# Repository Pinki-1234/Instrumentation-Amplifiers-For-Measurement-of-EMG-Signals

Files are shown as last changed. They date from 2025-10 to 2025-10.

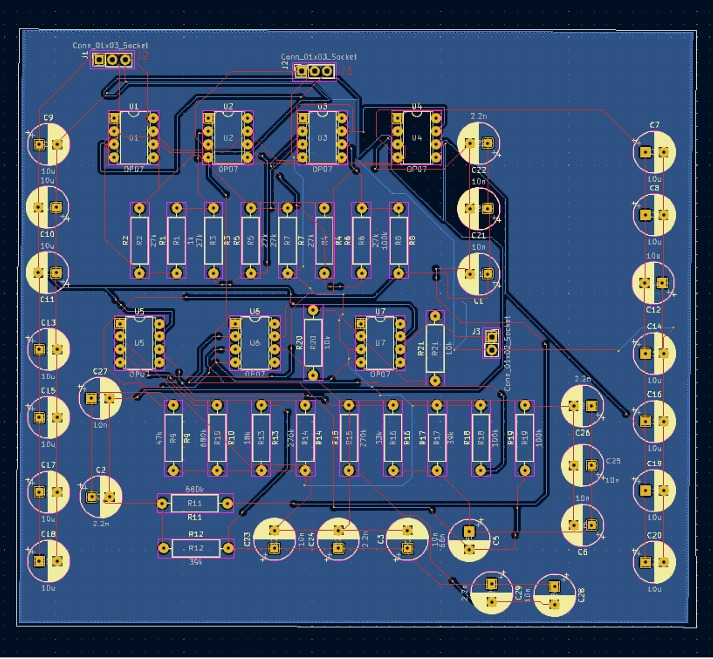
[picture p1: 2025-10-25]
PCB design.jpeg

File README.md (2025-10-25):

# Instrumentation Amplifiers for Measurement of EMG Signals

## Overview
This project focuses on designing and building an **Instrumentation Amplifier Circuit** specifically for measuring **Electromyography (EMG)** signals.  
The EMG signal is a bioelectrical signal produced by skeletal muscles, generally spanning **0.1 mV–5 mV** in amplitude and occupying a frequency range of **0–500 Hz**.  
To accurately capture and amplify this low-frequency, low-amplitude signal, the circuit design integrates both **high CMRR instrumentation amplification** and **selective bandpass filtering**, ensuring minimal noise interference and maximum fidelity.

---

## Objectives
- To design a **low-noise instrumentation amplifier** for biomedical EMG signal acquisition.  
- To achieve optimal **common-mode noise rejection** and **signal integrity**.  
- To implement a **bandpass filter** that passes frequencies relevant to EMG (50–150 Hz).  
- To validate the design using circuit simulations and performance testing.

---

## Project Architecture
The system is divided into two core functional blocks:

### 1. Instrumentation Amplifier Block
- Built using a **three-op-amp configuration** based on **OP07** operational amplifiers.  
- Provides high input impedance, excellent stability, and precise gain control.  
- Achieves an experimental gain of approximately **54 V/V**, aligning closely with the expected **55 V/V** value.  
- Ensures **high CMRR**, effectively filtering out common-mode interference and power-line noise.

### 2. Bandpass Filter Block
- Implements a **6th-order active bandpass filter** with a passband between **50 Hz and 250 Hz**.  
- Designed to preserve the EMG signal energy (primarily in 50–150 Hz) while blocking unwanted components.  
- Demonstrated strong attenuation of frequencies at **20 Hz** and **1 kHz**, confirming the filter’s effective roll-off characteristics.

---

## Circuit Design and Components
The project employs through-hole components, structured using **KiCad PCB Design Tools**.

### Key Components
- **ICs:** OP07 (x7)  
- **Resistors:** Ranging between 1 kΩ to 680 kΩ  
- **Capacitors:** 2.2 nF to 10 µF (radial THT)  
- **Connectors:** 2.54 mm pitch sockets for input/output  
- **Power Supply:** ±12 V DC dual supply  

### Tools Used
- **Simulation:** Tektronix TBS1072B Digital Oscilloscope  
- **PCB Design:** KiCad (schematic capture, footprint assignment, ERC, DRC)  
- **3D Visualization:** KiCad 3D Model View  

---

## Results and Testing

### Instrumentation Amplifier Testing:
- **Input:** 2 mV (differential, 180° out of phase)  
- **Output:** 216 mV  
- **Gain:** ~54 V/V (validated via oscilloscope readings)

### Filter Testing:
- **Input:** 100 mV sine wave at various frequencies  
- **20 Hz →** Output attenuated heavily  
- **100 Hz →** Signal passed cleanly  
- **1 kHz →** Output significantly reduced  

This confirms the amplifier–filter chain delivers the desired selective response and accuracy for EMG signal acquisition.

---

## PCB Design
The PCB was designed for compactness and low interference:

- **Schematic Capture:** Completed with correct symbol–footprint mapping  
- **Electrical Rule Check (ERC):** No major unconnected items or design violations  
- **Design Rule Check (DRC):** Verified compliance with layout standards  
- **3D View:** Ensured precise component placement for manufacturing  

---

## Applications
- Biomedical instrumentation, specifically **EMG signal measurement**  
- Medical research and muscle activity analysis  
- Biosignal processing and human–machine interface systems  
- Educational projects for analog circuit design and bioelectronics

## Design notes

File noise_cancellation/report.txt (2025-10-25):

Info: Processing symbol 'C1:Capacitor_SMD:C_0805_2012Metric'.
Info: Processing symbol 'C2:Capacitor_SMD:C_0805_2012Metric'.
Info: Processing symbol 'C3:Capacitor_SMD:C_0805_2012Metric'.
Info: Processing symbol 'C5:Capacitor_SMD:C_0805_2012Metric'.
Info: Processing symbol 'C6:Capacitor_SMD:C_0805_2012Metric'.
Info: Processing symbol 'C7:Capacitor_SMD:C_0805_2012Metric'.
Info: Processing symbol 'C8:Capacitor_SMD:C_0805_2012Metric'.
Info: Processing symbol 'C14:Capacitor_SMD:C_0805_2012Metric'.
Info: Processing symbol 'C9:Capacitor_SMD:C_0805_2012Metric'.
Info: Processing symbol 'C10:Capacitor_SMD:C_0805_2012Metric'.
Info: Processing symbol 'U5:Package_DIP:DIP-8_W7.62mm'.
Info: Processing symbol 'C11:Capacitor_SMD:C_0805_2012Metric'.
Info: Processing symbol 'C12:Capacitor_SMD:C_0805_2012Metric'.
Info: Processing symbol 'C13:Capacitor_SMD:C_0805_2012Metric'.
Info: Processing symbol 'U6:Package_DIP:DIP-8_W7.62mm'.
Info: Processing symbol 'C15:Capacitor_SMD:C_0805_2012Metric'.
Info: Processing symbol 'C16:Capacitor_SMD:C_0805_2012Metric'.
Info: Processing symbol 'C17:Capacitor_SMD:C_0805_2012Metric'.
Info: Processing symbol 'C18:Capacitor_SMD:C_0805_2012Metric'.
Info: Processing symbol 'C19:Capacitor_SMD:C_0805_2012Metric'.
Info: Processing symbol 'C20:Capacitor_SMD:C_0805_2012Metric'.
Info: Processing symbol 'C21:Capacitor_SMD:C_0805_2012Metric'.
Info: Processing symbol 'C22:Capacitor_SMD:C_0805_2012Metric'.
Info: Processing symbol 'C23:Capacitor_SMD:C_0805_2012Metric'.
Info: Processing symbol 'C24:Capacitor_SMD:C_0805_2012Metric'.
Info: Processing symbol 'C25:Capacitor_SMD:C_0805_2012Metric'.
Info: Processing symbol 'C26:Capacitor_SMD:C_0805_2012Metric'.
Info: Processing symbol 'C27:Capacitor_SMD:C_0805_2012Metric'.
Info: Processing symbol 'C28:Capacitor_SMD:C_0805_2012Metric'.
Info: Processing symbol 'C29:Capacitor_SMD:C_0805_2012Metric'.
Info: Processing symbol 'J1:Connector_PinSocket_2.54mm:PinSocket_1x03_P2.54mm_Vertical'.
Info: Processing symbol 'J2:Connector_PinSocket_2.54mm:PinSocket_1x03_P2.54mm_Vertical'.
Info: Processing symbol 'J3:Connector_PinSocket_2.54mm:PinSocket_1x02_P2.54mm_Vertical'.
Info: Processing symbol 'R1:Resistor_SMD:R_0805_2012Metric'.
Info: Processing symbol 'R2:Resistor_SMD:R_0805_2012Metric'.
Info: Processing symbol 'R3:Resistor_SMD:R_0805_2012Metric'.
Info: Processing symbol 'R4:Resistor_SMD:R_0805_2012Metric'.
Info: Processing symbol 'R5:Resistor_SMD:R_0805_2012Metric'.
Info: Processing symbol 'R6:Resistor_SMD:R_0805_2012Metric'.
Info: Processing symbol 'R7:Resistor_SMD:R_0805_2012Metric'.
Info: Processing symbol 'R8:Resistor_SMD:R_0805_2012Metric'.
Info: Processing symbol 'R9:Resistor_SMD:R_0805_2012Metric'.
Info: Processing symbol 'R10:Resistor_SMD:R_0805_2012Metric'.
Info: Processing symbol 'R11:Resistor_SMD:R_0805_2012Metric'.
Info: Processing symbol 'R12:Resistor_SMD:R_0805_2012Metric'.
Info: Processing symbol 'R13:Resistor_SMD:R_0805_2012Metric'.
Info: Processing symbol 'R14:Resistor_SMD:R_0805_2012Metric'.
Info: Processing symbol 'R15:Resistor_SMD:R_0805_2012Metric'.
Info: Processing symbol 'R16:Resistor_SMD:R_0805_2012Metric'.
Info: Processing symbol 'R17:Resistor_SMD:R_0805_2012Metric'.
Info: Processing symbol 'R18:Resistor_SMD:R_0805_2012Metric'.
Info: Processing symbol 'R19:Resistor_SMD:R_0805_2012Metric'.
Info: Processing symbol 'R20:Resistor_SMD:R_0805_2012Metric'.
Info: Processing symbol 'R21:Resistor_SMD:R_0805_2012Metric'.
Info: Processing symbol 'U1:Package_DIP:DIP-8_W7.62mm'.
Info: Processing symbol 'U7:Package_DIP:DIP-8_W7.62mm'.
Info: Processing symbol 'U2:Package_DIP:DIP-8_W7.62mm'.
Info: Processing symbol 'U3:Package_DIP:DIP-8_W7.62mm'.
Info: Processing symbol 'U4:Package_DIP:DIP-8_W7.62mm'.
Reconnected C10 pin 2 from Net-(J1-Pin_2) to Net-(J1-Pin_1).
Reconnected C8 pin 1 from Net-(J1-Pin_1) to Net-(J1-Pin_2).
Reconnected U1 pin 4 from Net-(J1-Pin_1) to Net-(J1-Pin_2).
Reconnected U1 pin 7 from Net-(J1-Pin_2) to Net-(J1-Pin_1).

Info: Total warnings: 0, errors: 0.

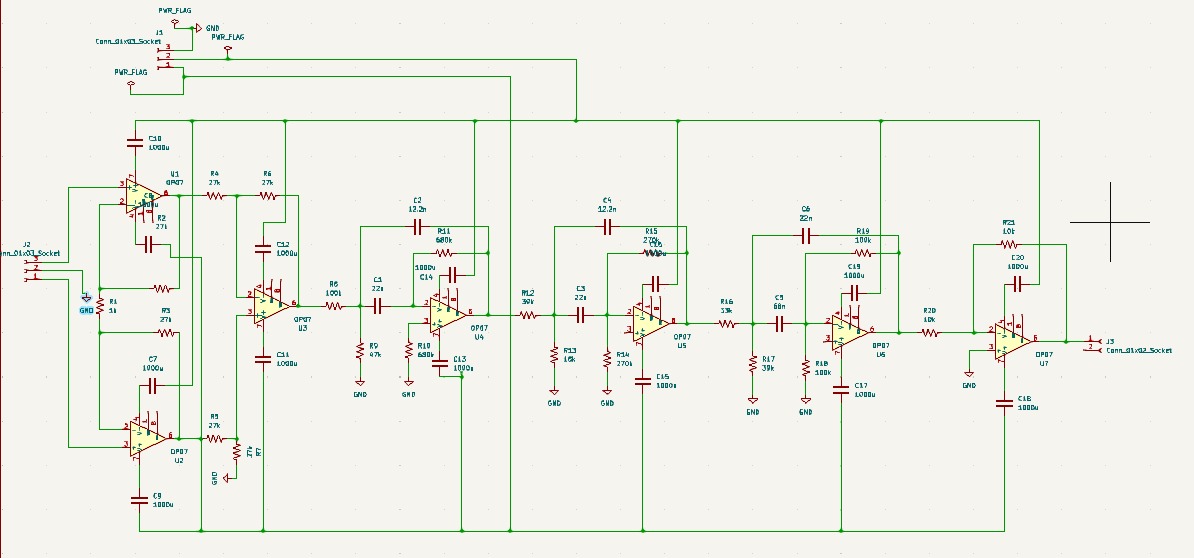
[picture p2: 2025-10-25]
Schematic diagram.jpeg

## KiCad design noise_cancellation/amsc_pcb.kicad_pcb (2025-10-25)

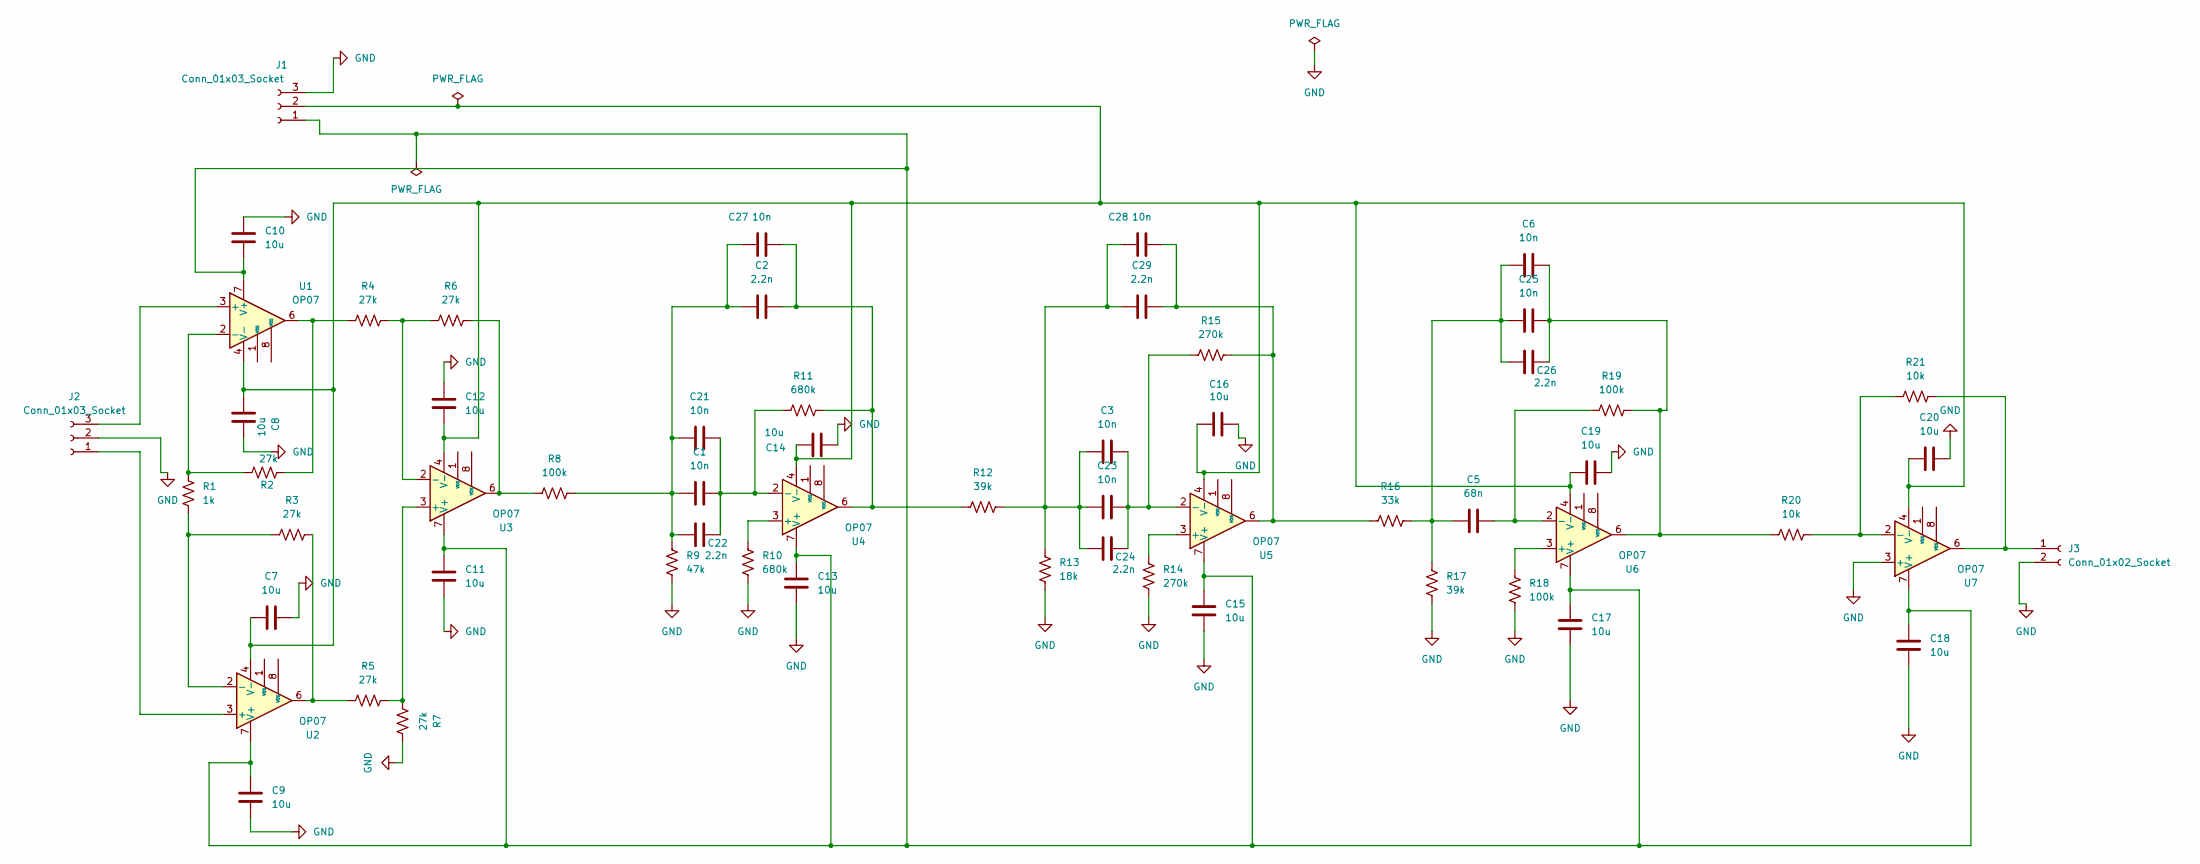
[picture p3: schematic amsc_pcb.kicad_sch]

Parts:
C1, C3, C6, C21, C23, C25, C27, C28: 10n; CP_Radial_D8.0mm_P3.50mm
C2, C22, C24, C26, C29: 2.2n; CP_Radial_D8.0mm_P3.50mm
C5: 68n; CP_Radial_D8.0mm_P3.50mm
C7, C8, C9, C10, C11, C12, C13, C14, C15, C16, C17, C18, C19, C20: 10u; CP_Radial_D8.0mm_P3.50mm
J1, J2: Conn_01x03_Socket; PinSocket_1x03_P2.54mm_Vertical
J3: Conn_01x02_Socket; PinSocket_1x02_P2.54mm_Vertical
R1: 1k; R_Axial_DIN0309_L9.0mm_D3.2mm_P12.70mm_Horizontal
R2, R3, R4, R5, R6, R7: 27k; R_Axial_DIN0309_L9.0mm_D3.2mm_P12.70mm_Horizontal
R8, R18, R19: 100k; R_Axial_DIN0309_L9.0mm_D3.2mm_P12.70mm_Horizontal
R9: 47k; R_Axial_DIN0309_L9.0mm_D3.2mm_P12.70mm_Horizontal
R10, R11: 680k; R_Axial_DIN0309_L9.0mm_D3.2mm_P12.70mm_Horizontal
R12, R17: 39k; R_Axial_DIN0309_L9.0mm_D3.2mm_P12.70mm_Horizontal
R13: 18k; R_Axial_DIN0309_L9.0mm_D3.2mm_P12.70mm_Horizontal
R14, R15: 270k; R_Axial_DIN0309_L9.0mm_D3.2mm_P12.70mm_Horizontal
R16: 33k; R_Axial_DIN0309_L9.0mm_D3.2mm_P12.70mm_Horizontal
R20, R21: 10k; R_Axial_DIN0309_L9.0mm_D3.2mm_P12.70mm_Horizontal
U1, U2, U3, U4, U5, U6, U7: OP07; DIP-8_W7.62mm

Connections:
GND: C7.2, C8.2, C9.2, C10.1, C11.1, C12.1, C13.2, C14.2, C15.2, C16.2, C17.2, C18.2, C19.2, C20.2, J1.3, J2.2, J3.2, R7.2, R9.2, R10.2, R13.2, R14.2, R17.2, R18.2, U7.3 (+)
unnamed: C1.1, C2.1, C21.1, C22.1, C27.1, R8.2, R9.1
unnamed: C2.2, C27.2, R11.2, R12.1, U4.6
unnamed: C3.1, C23.1, C24.1, C28.1, C29.1, R12.2, R13.1
unnamed: C5.1, C6.1, C25.1, C26.1, R16.2, R17.1
unnamed: C6.2, C25.2, C26.2, R19.2, R20.1, U6.6
unnamed: C28.2, C29.2, R15.2, R16.1, U5.6
unnamed: C9.1, C10.2, C11.2, C13.1, C15.1, C17.1, C18.1, J1.1, U1.7 (V+), U2.7 (V+), U3.7 (V+), U4.7 (V+), U5.7 (V+), U6.7 (V+), U7.7 (V+)
unnamed: C7.1, C8.1, C12.2, C14.1, C16.1, C19.1, C20.1, J1.2, U1.4 (V-), U2.4 (V-), U3.4 (V-), U4.4 (V-), U5.4 (V-), U6.4 (V-), U7.4 (V-)
unnamed: J2.1, U2.3 (+)
unnamed: J2.3, U1.3 (+)
unnamed: J3.1, R21.2, U7.6
unnamed: R2.2, R4.1, U1.6
unnamed: R3.2, R5.1, U2.6
unnamed: R6.2, R8.1, U3.6
unnamed: R1.1, R2.1, U1.2 (-)
unnamed: R1.2, R3.1, U2.2 (-)
unnamed: R5.2, R7.1, U3.3 (+)
unnamed: R4.2, R6.1, U3.2 (-)
unnamed: R10.1, U4.3 (+)
unnamed: C1.2, C21.2, C22.2, R11.1, U4.2 (-)
unnamed: R14.1, U5.3 (+)
unnamed: C3.2, C23.2, C24.2, R15.1, U5.2 (-)
unnamed: R18.1, U6.3 (+)
unnamed: C5.2, R19.1, U6.2 (-)
unnamed: R20.2, R21.1, U7.2 (-)

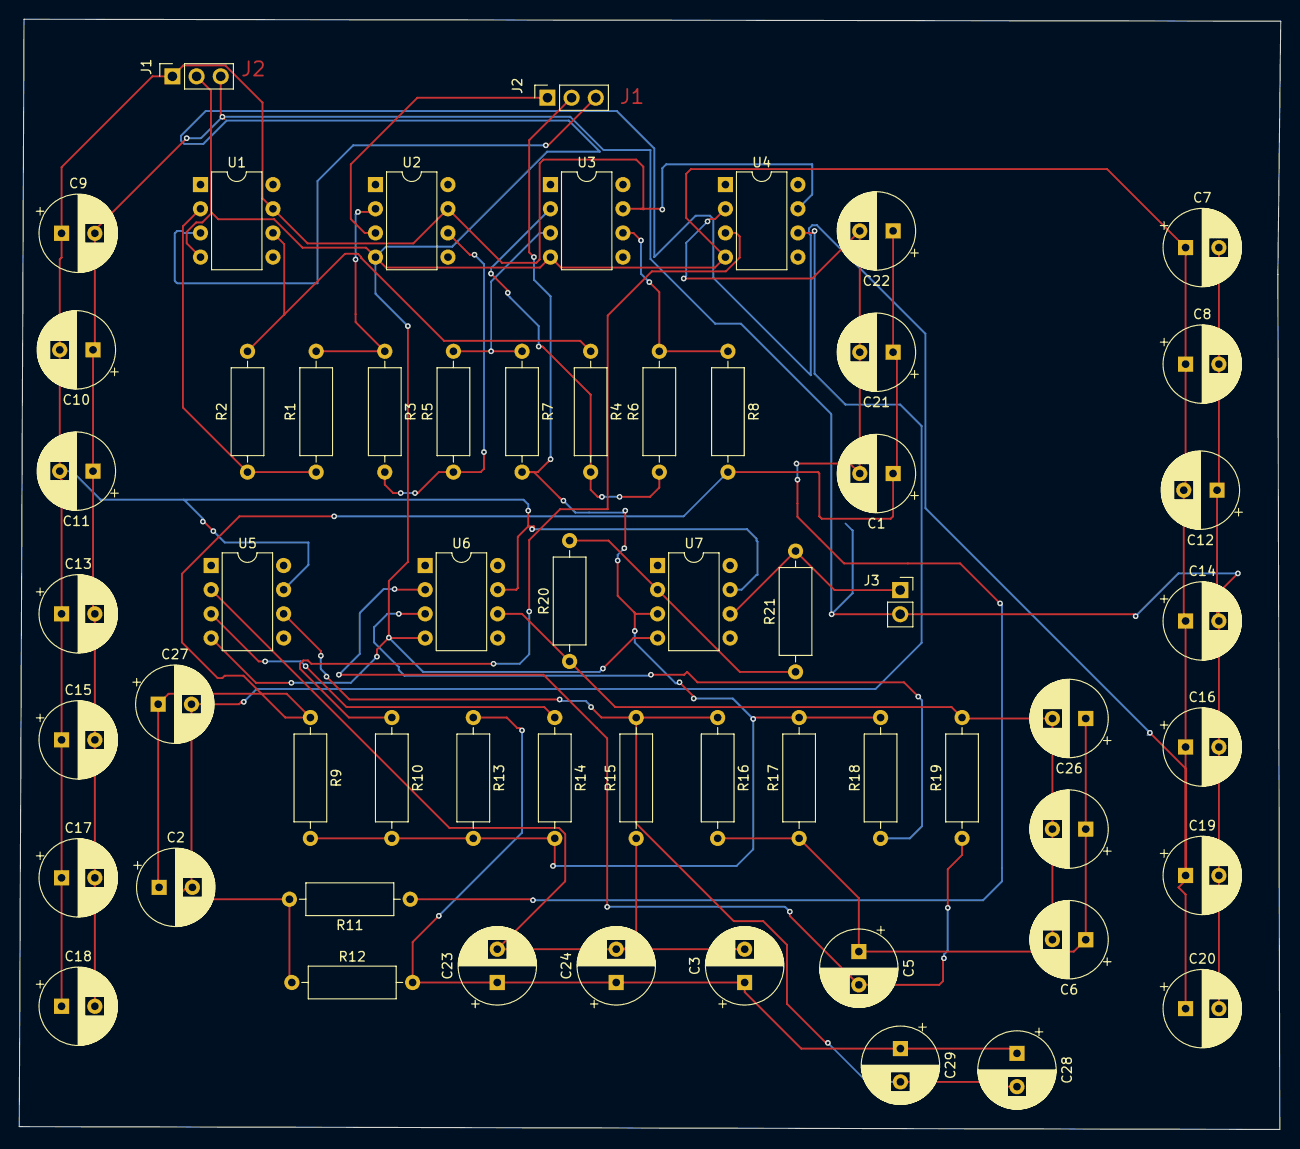
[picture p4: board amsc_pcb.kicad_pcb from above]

Board: 2 copper layers, 132.6 x 116.7 mm, 59 parts (0 on the bottom side), 26 nets.

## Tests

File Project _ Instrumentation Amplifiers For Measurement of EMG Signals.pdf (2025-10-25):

Project Title: Instrumentation Amplifiers For Measurement of EMG Signals TA Name: Sapna kumari

The project aims to design and build a low-noise amplifier tailored for EMG (electromyography) signals, which typically have low voltages ranging from 0.1 mV to 5 mV and frequencies between 0 and 500 Hz. EMG signals are inherently delicate, and most of the signal's energy is concentrated in the 50 to 150 Hz range. This project seeks to amplify these low-voltage signals effectively while minimizing noise, ensuring the amplified signal retains its original characteristics as closely as possible.

To achieve these goals, the design is divided into two main functional blocks:

1. Instrumentation Amplifier Block:
This first block uses a three-op-amp instrumentation amplifier configuration, chosen for its high common-mode rejection ratio (CMRR) and low power consumption. An instrumentation amplifier is essential here because it will reduce common-mode noise, which can arise from environmental interference or other external sources. By canceling this common noise, the instrumentation amplifier ensures that the useful EMG signal is preserved and amplified accurately. This configuration is particularly effective for biomedical applications due to its ability to handle differential signals and its stable gain settings.
2. Bandpass Filter Block:
Following the instrumentation amplifier, the signal passes through a 6th-order bandpass filter, specifically designed to pass frequencies within a range of 50 Hz to 250 Hz. This range includes the frequency band where most of the EMG signal's energy resides (50 to 150 Hz) while filtering out noise outside this band. The 6th-order design provides a steep roll-off outside the passband, which helps further reduce any unwanted low-frequency drift and high-frequency noise, resulting in a cleaner signal. The filter’s bandwidth is set at approximately 200 Hz, allowing for an effective trade-off between filtering precision and preserving the essential components of the EMG signal.

This amplifier is designed for EMG applications, where low noise and signal integrity are critical. The combination of a high-quality instrumentation amplifier and a selective bandpass filter ensures that the final amplified signal is both clear and highly representative of the original EMG activity. This approach is commonly used in biomedical engineering, where capturing accurate physiological signals is vital for reliable analysis and diagnostics.

Instrumentation amplifier Block:

Circuit Diagram:

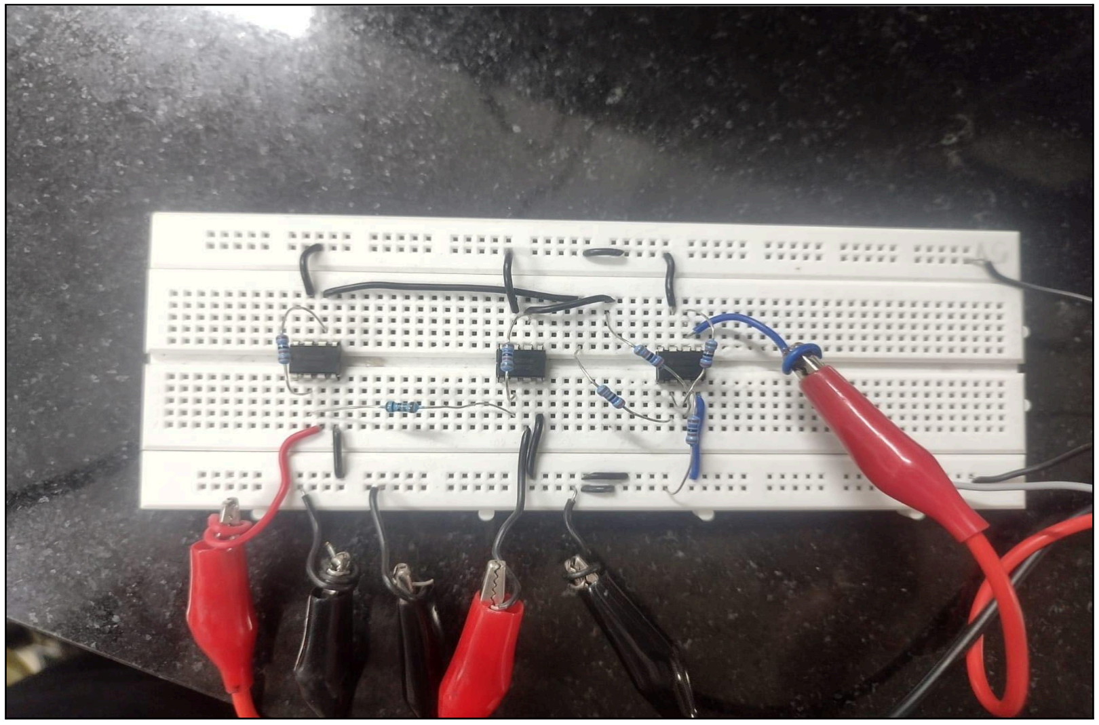
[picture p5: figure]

We tested the circuit by applying a common-mode input signal of 2 mV peak-to-peak, with the inputs of the instrumentation amplifier set 180 degrees out of phase. The calculated gain was 55 V/V. Observing the output, we got 216 mV, giving an actual gain of 54 V/V, which is very close to our expected value. This indicates that the instrumentation amplifier is functioning correctly.

Output:

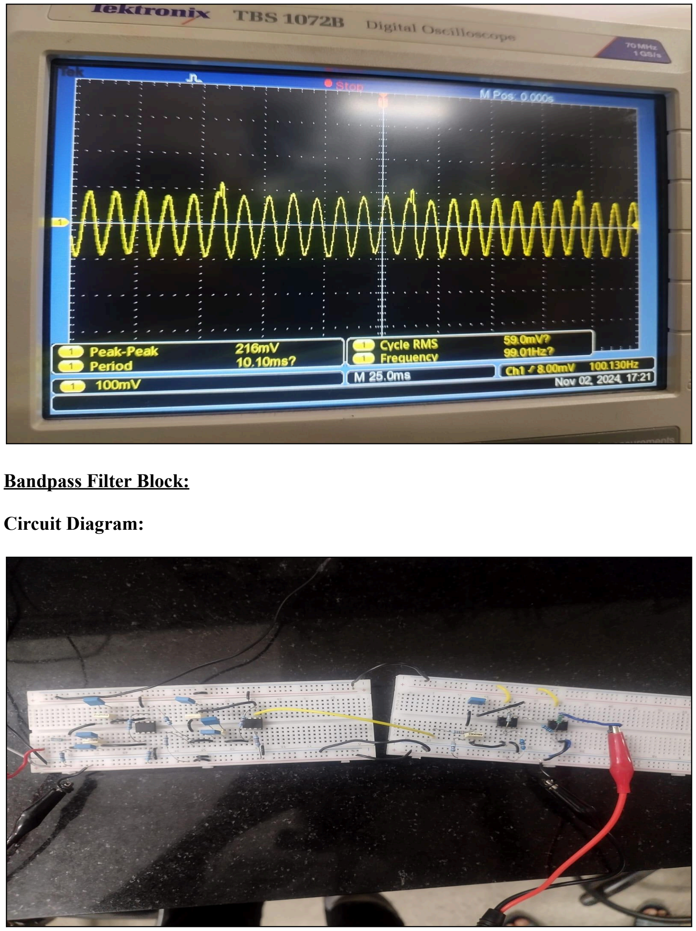
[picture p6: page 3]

Bandpass Filter Block:

Circuit Diagram:

To test the bandpass filter, we applied a 100 mV input signal. At a frequency of 20 Hz, we observed the output was significantly attenuated. This clearly shows that the filter is effectively blocking frequencies outside its passband.

Output:

(frequency of 20 Hz)

At a frequency of 20 Hz, we observed the output was significantly attenuated. This clearly shows that the filter is effectively blocking frequencies outside its passband.

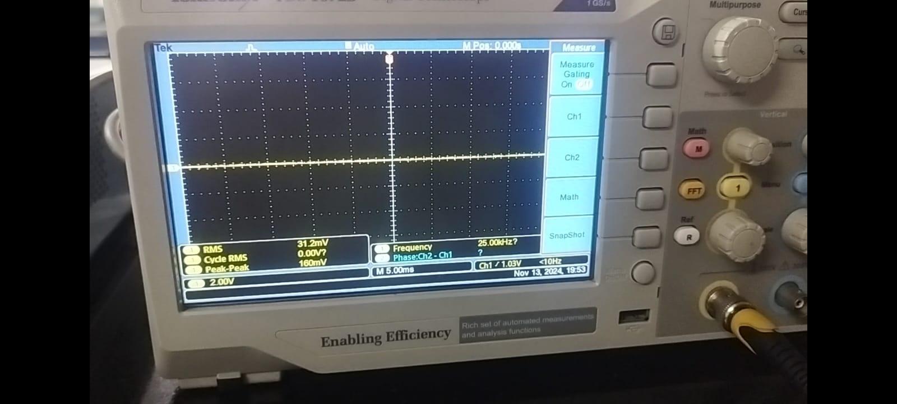
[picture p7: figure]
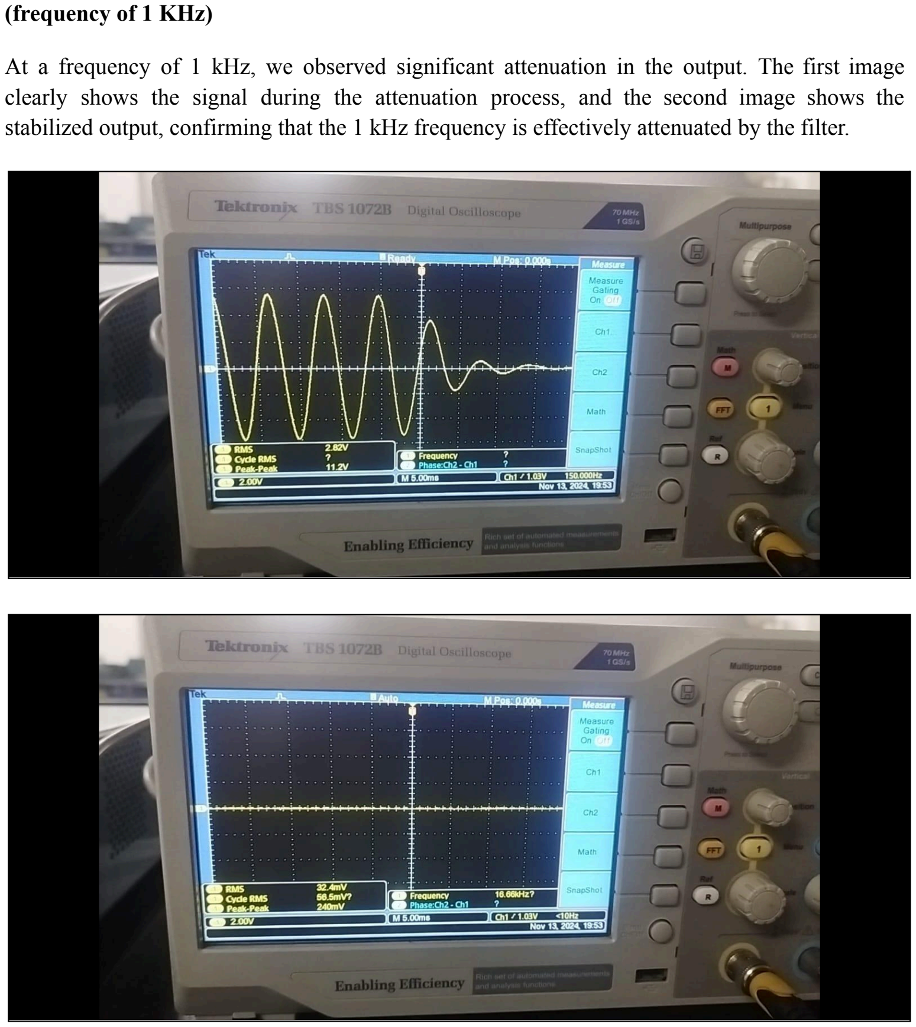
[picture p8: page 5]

(frequency of 1 KHz)

At a frequency of 1 kHz, we observed significant attenuation in the output. The first image clearly shows the signal during the attenuation process, and the second image shows the stabilized output, confirming that the 1 kHz frequency is effectively attenuated by the filter.

PCB design:

- Screenshot of Schematic diagram :

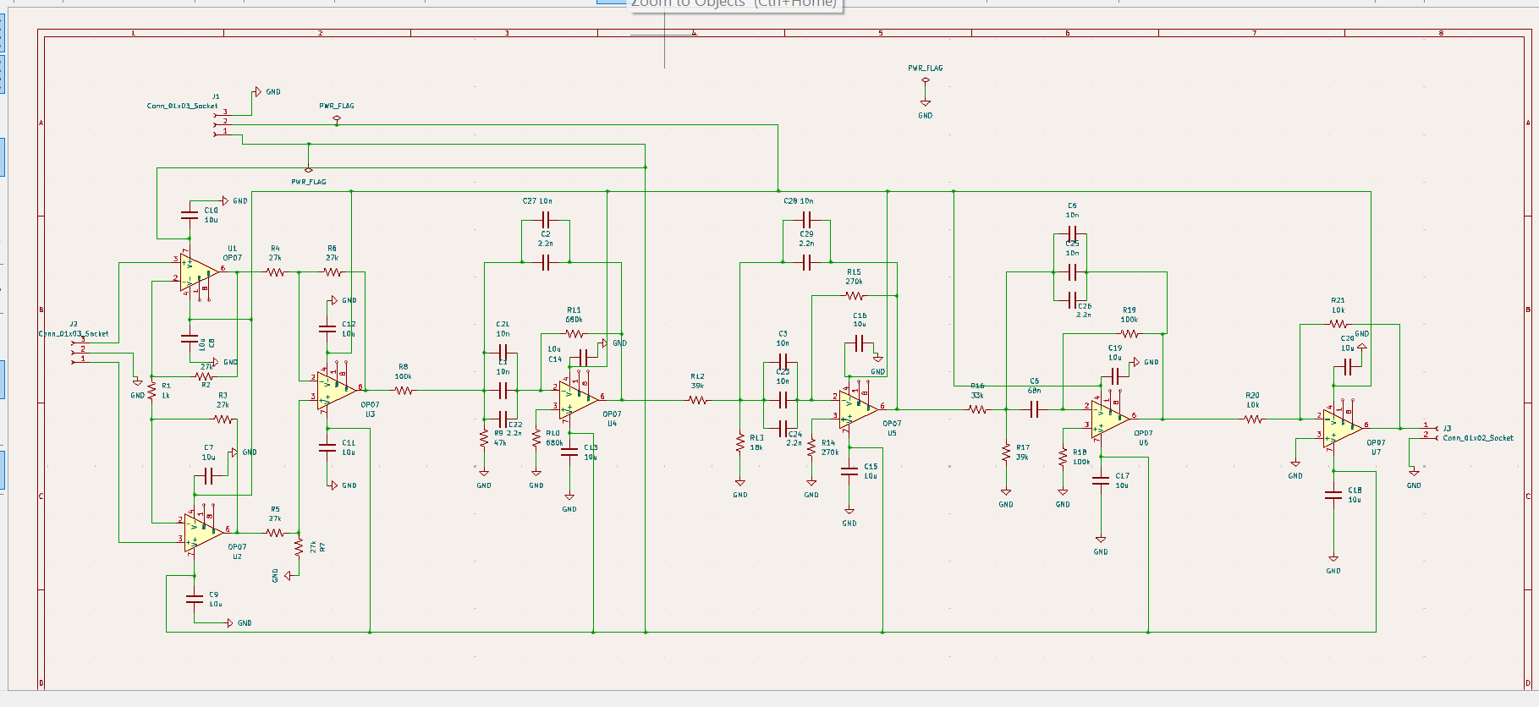
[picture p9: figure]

Fig.1 Schematic diagram
- Footprint Assignment table :

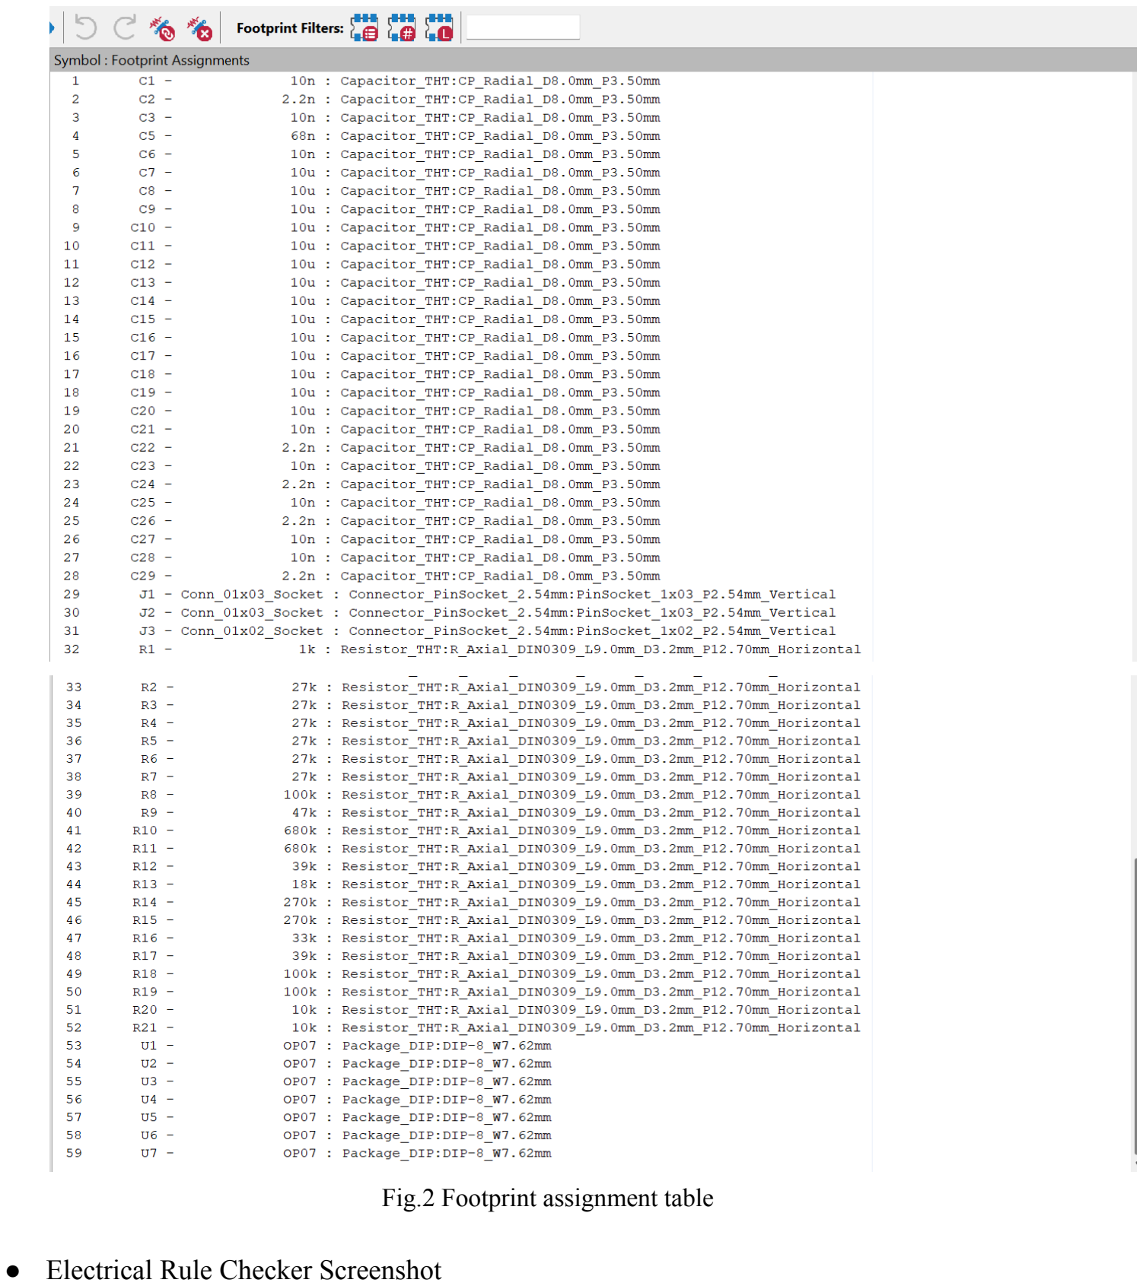
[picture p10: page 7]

Fig.2 Footprint assignment table

- Electrical Rule Checker Screenshot

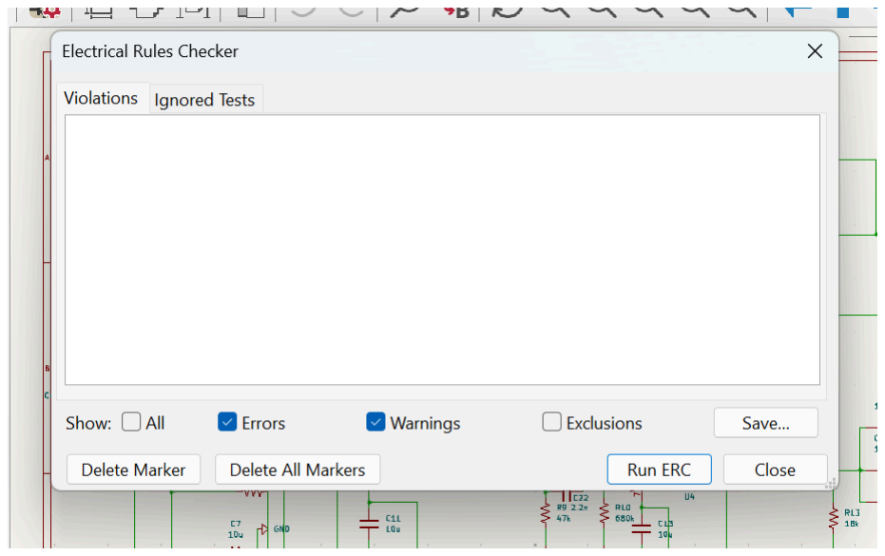
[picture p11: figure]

Fig.3 Electrical rule checker

- PCB layout of the circuit

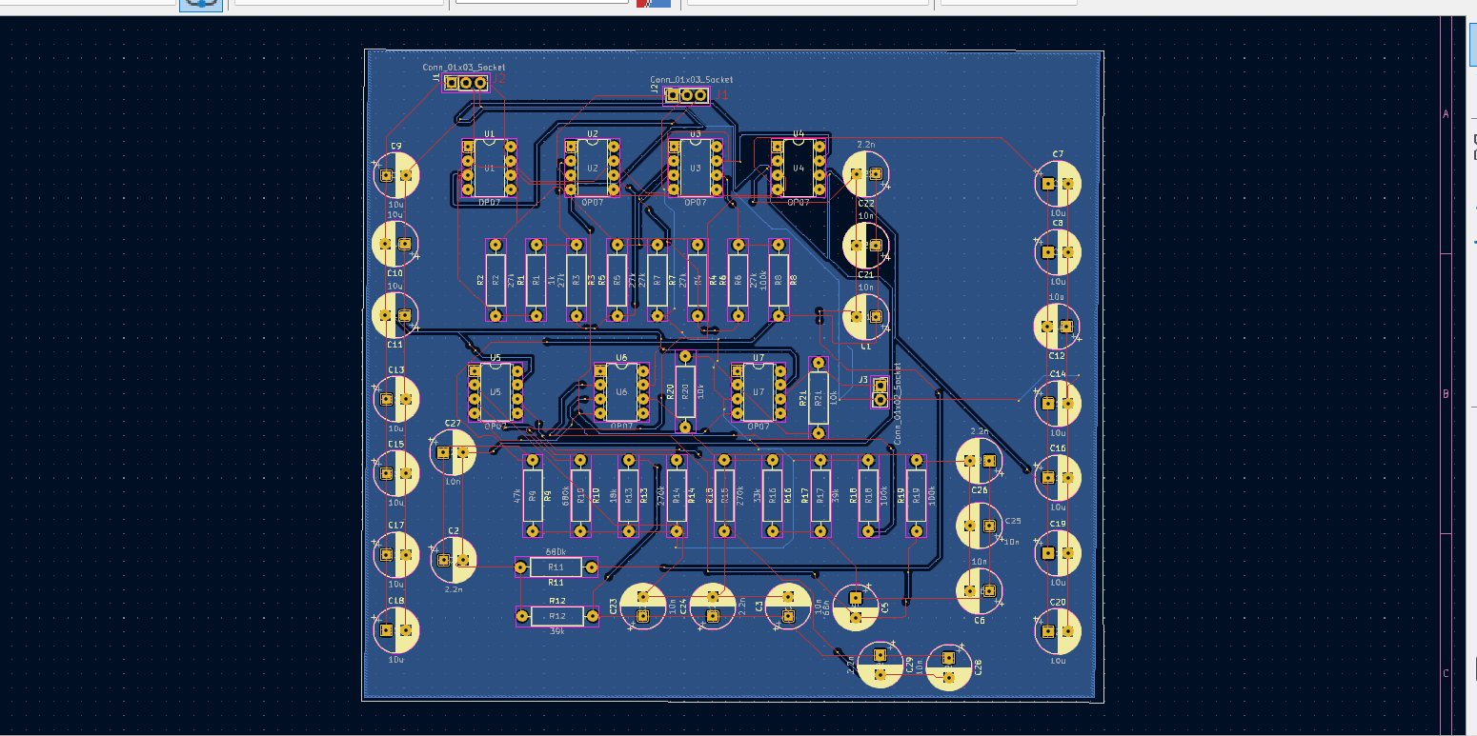
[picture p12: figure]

Fig.3 PCB design

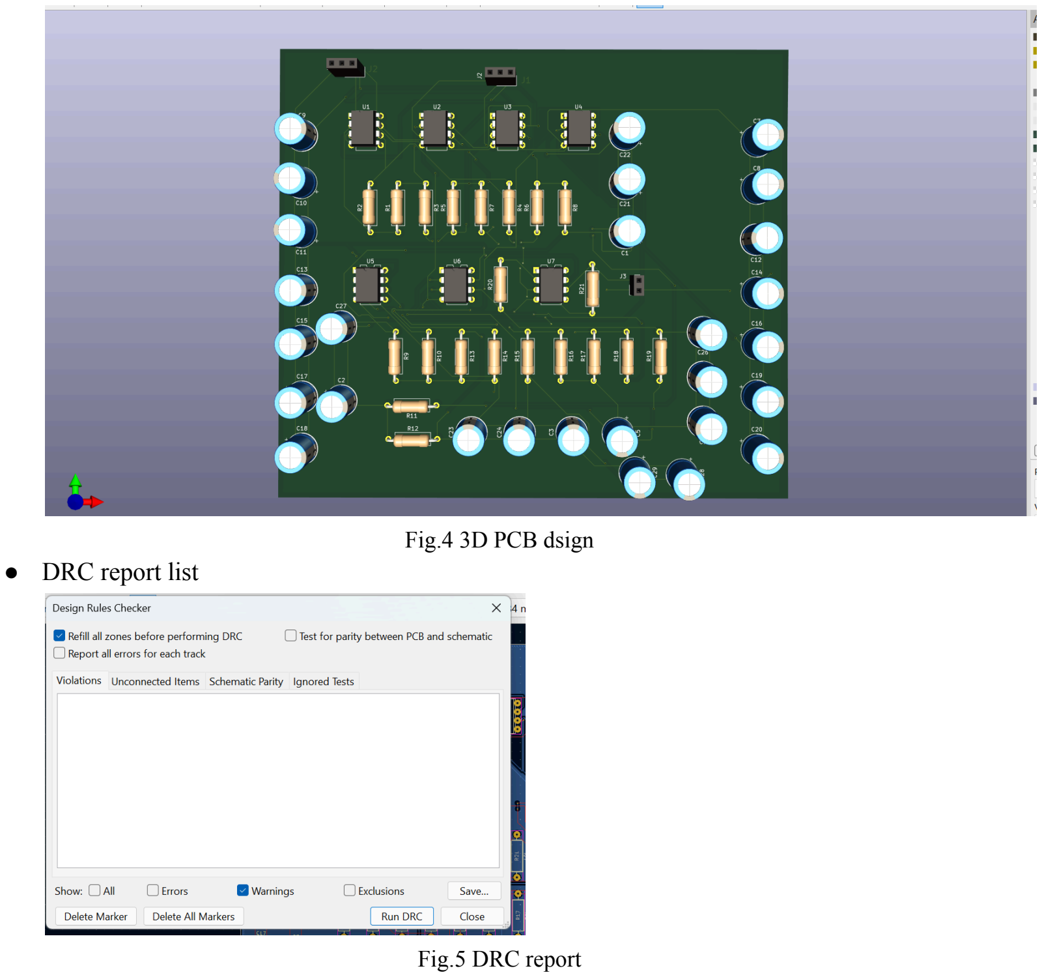
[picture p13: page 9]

Fig.4 3D PCB dsign
- DRC report list

Fig.5 DRC report
